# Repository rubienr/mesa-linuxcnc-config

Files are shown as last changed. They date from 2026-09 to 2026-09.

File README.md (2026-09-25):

# LinuxCNC workspace

This repository records the LinuxCNC host, runtime tooling, Mesa communication
benchmark, current machine evidence, and the staged Frida migration from the
BeagleBone/Panther controller to a Mesa 7I95T.

## Project map

| Area | Purpose | Status |
| --- | --- | --- |
| [`archlinux/`](archlinux/) | Arch Linux, PREEMPT_RT, driver, BIOS, and CPU-isolation setup | Host installation record |
| [`config/`](config/) | Affinity and launcher scripts plus `config/frida-mesa/` | Runtime tooling and unverified commissioning profile |
| [`mesa-benchmark/`](mesa-benchmark/) | Repeatable 1 ms/2 ms HostMot2 Ethernet test | Communication-only; not machine control |
| [`hardware-documentation/current/`](hardware-documentation/current/) | Verified hardware, recovered settings, migration evidence, and open work | Current documentation source of truth |
| [`hardware-documentation/legacy/`](hardware-documentation/legacy/) | BBB/Panther schematics and Machinekit configuration | Forensic evidence only |

## Source-of-truth boundaries

- Host installation and tuning rationale: `archlinux/README.md`.
- Runtime CPU/IRQ enforcement: scripts under `config/`.
- Frida LinuxCNC behavior and proposed terminal allocation:
  `config/frida-mesa/` and its `wiring.csv`.
- Current physical-machine facts: topic documents under
  `hardware-documentation/current/`.
- Historical files under `hardware-documentation/legacy/` must be verified
  before their values are reused.

Start with the README in the relevant area. AI coding agents must follow the
root and nearest scoped `AGENTS.md` files before changing this workspace.

## Synchronizing to the target

After making local changes, synchronize the complete workspace to the target
checkout before target-host testing:

```console
./tools/sync-to-target.sh
```

Use `./tools/sync-to-target.sh --dry-run` to preview changes. The wrapper
transfers the workspace to `frida@frida:~/linuxcnc/` over SSH,
excludes `.git`, and does not delete files that exist only on the target.
`TARGET_SSH_DESTINATION` and `TARGET_WORKSPACE` provide explicit overrides when
needed. Generated diagnostic logs, monitor locks, and archived diagnostic runs
remain target-local; only the tracked log-directory placeholders are copied.

## Convenience launchers

From the repository root, `./linuxcnc-start.sh /path/to/config.ini` forwards an
explicit INI to `config/linuxcnc-start.sh` after interactively applying and
checking IRQ affinity. LinuxCNC RTAPI creates its realtime task on CPU 11 via
`RTAPI_CPU_NUMBER`; a second unprivileged check is logged after the task
appears. To launch the communication-only 1 ms Mesa profile in a detached
screen session, use:

```console
./linuxcnc-benchmark-mesa-1ms.sh
screen -r mesa-benchmark-1ms
```

The benchmark launcher refuses to run when it detects an existing LinuxCNC,
LinuxCNC server, or RTAPI process. Override only the screen session name with
`MESA_SCREEN_SESSION`. Affinity logs are written privately below
`mesa-benchmark/diagnostic-logs/`. A failed pre-start affinity check is logged
as a warning and does not prevent startup because the LinuxCNC realtime task
does not exist yet. A setter failure remains fatal, and the delayed post-start
check records the authoritative realtime-task placement.

Run the affinity tools directly from the repository root with:

```console
./thread-affinity-check.sh --brief
./thread-affinity-set.sh
```

These convenience scripts delegate all arguments to their counterparts below
`config/`; the root setter invokes `sudo` and therefore retains its interactive
password prompt.

Manage the graphics stress load and show a concise runtime overview from the
repository root with:

```console
./glxgears-restart.sh
./glxgears-stop.sh
./runtime-status.sh
```

The stop helper stops only the managed `mesa-glxgears-stress.service` and
reports unrelated surviving `glxgears` processes instead of killing them.

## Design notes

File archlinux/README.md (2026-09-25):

# LinuxCNC on Arch Linux with PREEMPT_RT

This is the working installation and tuning record for a Lenovo ThinkCentre
M75q Gen 2 (type 11JK) with a Ryzen 5 PRO 4650GE and Mesa 7I95T. It deliberately
records the Arch-specific failures encountered during setup.

Validated package and firmware versions at the time of writing:

```text
BIOS               M3CKT3EA / 1.62 (2026-01-15)
kernel             linux-rt 7.2.6.rt3.arch1-1
LinuxCNC           2.9.10-1
Mesa utility       mesaflash-git 3.4.9.r33.g11e6f85-1
Realtek driver     r8168-dkms 8.057.00-2
BLT                2.4z-12 (locally patched)
Tcl/Tk             8.6.16-1
```

## 1. Install the realtime kernel

```bash
sudo pacman -Syu
sudo pacman -S linux-rt linux-rt-headers
sudo grub-mkconfig -o /boot/grub/grub.cfg
sudo reboot
```

If `grub-mkconfig` produces only firmware and snapshot entries, verify that
GRUB's Linux generator is executable. This permission was wrong on the
validated installation:

```bash
ls -l /etc/grub.d/10_linux
sudo chmod 755 /etc/grub.d/10_linux
sudo grub-mkconfig -o /boot/grub/grub.cfg
```

After rebooting, verify PREEMPT_RT rather than relying only on the kernel name:

```bash
uname -r
cat /sys/kernel/realtime
```

The second command must print `1`.

## 2. Install build prerequisites and LinuxCNC

Install the normal Arch build tools and `hostname`. The missing `hostname`
program caused part of the LinuxCNC build/runtime setup to fail; on Arch it is
provided by `inetutils`:

```bash
sudo pacman -S --needed base-devel git inetutils
command -v hostname
pacman -Qo /usr/bin/hostname
```

Install the stable LinuxCNC package and current Mesa utility from the AUR:

```bash
yay -S linuxcnc
yay -S mesaflash-git
```

The tested installation uses stable `linuxcnc 2.9.10-1`, not
`linuxcnc-git`. The Git package may be newer but is a moving development
target and is unnecessary for this benchmark.

Verify the realtime helper. The leading `s` in the owner execute position is
intentional for this package:

```bash
pacman -Q linuxcnc
ls -l /usr/bin/rtapi_app
```

Expected permissions begin with `-rwsr-xr-x`. Do not run `modprobe rtapi`:
this configuration uses userspace RTAPI on PREEMPT_RT, so there is no `rtapi`
kernel module. The misleading module message from `halcmd` can also appear
when no LinuxCNC realtime session is running or when `halcmd` is invoked as a
different user.

## 3. Build the BLT Tcl/Tk extension correctly

BLT is required by Tcl/Tk-based tools such as the LinuxCNC latency histogram.
The unmodified AUR `blt` recipe failed in two ways on this system:

- GCC rejected the old spline callback declarations with `too many arguments
  to function` under the newer C language rules.
- `libBLT24.so` was initially built without Tcl/Tk dependencies and later
  failed with an undefined `Tk_MeasureChars` symbol.

Clone the AUR recipe, apply the included patch, and force a clean rebuild:

```bash
mkdir -p "$HOME/builds"
cd "$HOME/builds"
git clone https://aur.archlinux.org/blt.git
cd blt
patch -Np1 < "$HOME/linuxcnc/archlinux/blt-PKGBUILD.patch"
makepkg -Cfsi
```

`-f` matters if an earlier package file exists; `makepkg -Csi` alone can end
up reinstalling an already-built broken package instead of producing the
intended replacement.

Confirm that BLT is linked against both Tk and Tcl:

```bash
readelf -d /usr/lib/libBLT24.so | grep NEEDED
```

The output must include at least `libtk8.6.so` and `libtcl8.6.so` in addition
to the usual system libraries.

Some LinuxCNC latency utilities are intended for a source-tree Run In Place
(RIP) environment. The Mesa benchmark in the sibling directory does not
require a RIP installation.

## 4. Replace `r8169` with `r8168-dkms`

The exact PCI device in the tested computer is:

```text
Realtek RTL8111/8168/8211/8411 PCI Express Gigabit Ethernet Controller
PCI ID:          10ec:8168, revision 15
Subsystem:       Lenovo 17aa:3190
Firmware:        rtl8168h-2_0.0.2 (2015-02-26)
PCI address:     0000:01:00.0
```

The realtime kernel's in-tree `r8169` driver produced rapidly increasing Mesa
packet errors and millisecond-scale HostMot2 read delays on this controller.
The AUR `r8168-dkms` driver was materially better.

The realtime headers must be installed so DKMS builds for `linux-rt`:

```bash
sudo pacman -S --needed dkms linux-rt-headers
yay -S r8168-dkms
sudo mkinitcpio -P
sudo reboot
```

The package installs `/usr/lib/modprobe.d/r8168-dkms.conf` containing:

```text
blacklist r8169
```

Verify the active driver after rebooting:

```bash
lspci -nnk -s 01:00.0
ethtool -i enp1s0
```

The first line must be `driver: r8168`. On the validated system it reports
version `8.057.00-NAPI`.

Configure the dedicated Mesa interface without a gateway or DNS server:

```bash
sudo nmcli connection modify "Mesa LAN" \
    connection.interface-name enp1s0 \
    ipv4.method manual \
    ipv4.addresses 192.168.1.111/24 \
    ipv4.gateway "" \
    ipv4.dns "" \
    ipv4.never-default yes \
    ipv6.method disabled
sudo nmcli connection up "Mesa LAN"
ping -c 3 192.168.1.121
```

## 5. Kernel command line and CPU isolation

A representative `/proc/cmdline` is shown below. The root filesystem UUID is
an installation-specific metavalue, not a UUID that should be copied:

```text
BOOT_IMAGE=/vmlinuz-linux-rt root=UUID=<ROOT_FILESYSTEM_UUID> rw rootflags=subvol=@ loglevel=3 quiet ipv6.disable=1 isolcpus=domain,managed_irq,5,11 nohz_full=5,11 rcu_nocbs=5,11 irqaffinity=0-4,6-10
```

GRUB generates the real `root=UUID=...` argument for the installed root
filesystem. Leave that generation to GRUB; only add the tuning parameters to
`GRUB_CMDLINE_LINUX_DEFAULT`.

The tuning portion in `/etc/default/grub` is:

```bash
GRUB_CMDLINE_LINUX_DEFAULT="loglevel=3 quiet ipv6.disable=1 isolcpus=domain,managed_irq,5,11 nohz_full=5,11 rcu_nocbs=5,11 irqaffinity=0-4,6-10"
```

`ipv6.disable=1` disables IPv6 system-wide at boot: interfaces receive no IPv6
addresses and applications cannot open IPv6 sockets. Use it only when the
Wi-Fi/SSH network is known to work over IPv4. Remove the parameter and reboot
if IPv6 is needed later; see the
[Linux kernel IPv6 documentation](https://www.kernel.org/doc/html/latest/networking/ipv6.html).

The Ryzen 5 PRO 4650GE presents two logical CPUs per physical core. The tested
allocation is:

| Physical core | Logical CPUs | Intended role |
| --- | --- | --- |
| 0 | 0 / 6 | Housekeeping, desktop, stress workers, and Wi-Fi IRQs |
| 1 | 1 / 7 | Housekeeping, desktop, stress workers, and Wi-Fi IRQs |
| 2 | 2 / 8 | CPU 2 idle; CPU 8 dedicated to the Mesa Ethernet IRQ during tests |
| 3 | 3 / 9 | Housekeeping, desktop, stress workers, and Wi-Fi IRQs |
| 4 | 4 / 10 | Housekeeping, desktop, stress workers, and Wi-Fi IRQs |
| 5 | 5 / 11 | CPU 5 isolated and idle; CPU 11 isolated for the LinuxCNC servo thread |

Only CPUs 5 and 11 are kernel-isolated. CPUs 2 and 8 are reserved operationally
by excluding them from the stress workload, pinning the Mesa IRQ to CPU 8, and
keeping Wi-Fi IRQs away from both siblings.

Regenerate the configuration and reboot after changing it:

```bash
sudo grub-mkconfig -o /boot/grub/grub.cfg
sudo reboot
cat /proc/cmdline
cat /sys/devices/system/cpu/isolated
cat /sys/devices/system/cpu/nohz_full
ip -6 address
```

CPUs 5 and 11 should be listed as isolated/nohz-full CPUs. The LinuxCNC FIFO
servo thread runs on CPU 11 and CPU 5 is its idle SMT sibling. With
`ipv6.disable=1`, `ip -6 address` should show no IPv6 addresses.

## 6. Network IRQ placement

CPU isolation does not automatically keep every managed MSI-X vector away
from isolated CPUs. The Intel AX200 Wi-Fi driver initially placed vectors on
both CPU 5 and CPU 11. IRQ numbers also change after each reboot.

Reserve physical core CPU2/8 for Mesa, using CPU 8 for the LAN IRQ, and keep
Wi-Fi away from CPUs 2, 5, 8, and 11:

```bash
LAN_IRQ=$(ls /sys/class/net/enp1s0/device/msi_irqs)
echo 8 | sudo tee "/proc/irq/$LAN_IRQ/smp_affinity_list"

for IRQ in $(ls /sys/class/net/wlp2s0/device/msi_irqs); do
    CPU=$(cat "/proc/irq/$IRQ/effective_affinity_list")
    case "$CPU" in
        2)  TARGET=1 ;;
        5)  TARGET=4 ;;
        8)  TARGET=7 ;;
        11) TARGET=10 ;;
        *)  continue ;;
    esac
    echo "$TARGET" | sudo tee "/proc/irq/$IRQ/smp_affinity_list"
done
```

Some Wi-Fi effective affinities update only after another interrupt. Verify
both requested and effective affinity before starting LinuxCNC:

```bash
for DEV in enp1s0 wlp2s0; do
    echo "=== $DEV ==="
    for IRQ in $(ls "/sys/class/net/$DEV/device/msi_irqs"); do
        printf 'IRQ %-3s requested=' "$IRQ"
        cat "/proc/irq/$IRQ/smp_affinity_list"
        printf '        effective='
        cat "/proc/irq/$IRQ/effective_affinity_list"
    done
done
```

These runtime assignments are not persistent across reboot. Reapply them
after boot until a dedicated systemd unit is installed.

The maintained workspace scripts implement the same dynamic IRQ discovery and
check the LinuxCNC FIFO task once it exists:

```bash
sudo "$HOME/linuxcnc/config/thread-affinity-set.sh"
"$HOME/linuxcnc/config/thread-affinity-check.sh"
```

Run the setter once after boot for the network IRQs. Normal launchers set
`RTAPI_CPU_NUMBER=11` before LinuxCNC creates its realtime task. Use the
setter's explicit `--repair-running-rt` mode only when the post-start check
finds incorrect placement.

The reproducible stress affinity deliberately excludes the two realtime and
two Mesa-network CPUs:

```bash
taskset -c 0-1,3-4,6-7,9-10 \
    stress-ng --cpu 8 --vm 2 --vm-bytes 2G --timeout 24h
```

## 7. BIOS configuration

Installed firmware: Lenovo `M3CKT3EA / 1.62`. The following settings were
applied for the current test:

```text
WirelessLANAccess                 Enabled (required for SSH)
Bluetooth                        Disabled
CStateSupport                    Disabled
ASPMSupport                      Disabled
EnhancedPowerSavingMode          Disabled
OnboardAudioController           Disabled
AMDSecureVirtualMachine (SVM)    Disabled
IOMMU                            Disabled
DASHSupport                      Disabled
Integrated GPU UMA framebuffer   2 GiB
```

The cooling mode was left unchanged; `Full speed` was not selected.
`CPBMode` (AMD boost) was also left unchanged. Change one variable at a time
if either option is tested later.

At runtime, this BIOS configuration results in:

```bash
cat /sys/devices/system/cpu/cpuidle/current_driver
```

printing `none`, confirming that the previous ACPI C2/C3 idle states are no
longer active.

## 8. Final checks

Before a benchmark or machine session, check:

```bash
cat /sys/kernel/realtime
cat /proc/cmdline
ethtool -i enp1s0
ip -4 address show enp1s0
ip -6 address
ping -c 3 192.168.1.121
ls -l /usr/bin/rtapi_app
```

Expected essentials are realtime `1`, the isolation parameters above,
`ipv6.disable=1` when the system-wide IPv6 policy is selected, `r8168`, address
`192.168.1.111/24`, no IPv6 addresses, a reachable Mesa card, and setuid
permissions on `rtapi_app`.

Use `../config/README.md` for the normal operating sequence and
`../mesa-benchmark/README.md` for the 1 ms/2 ms benchmark, load
generation, counters, and safety constraints.

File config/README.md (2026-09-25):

# LinuxCNC runtime and machine configurations

This directory contains the shared CPU/IRQ affinity and launcher scripts plus
the staged Frida Mesa 7I95T commissioning profile under `frida-mesa/`. IRQ
numbers are discovered dynamically because they can change at boot.

## CPU and IRQ layout

| Logical CPU | Intended use |
| --- | --- |
| 0, 1, 3, 4, 6, 7, 9, 10 | Housekeeping, desktop, stress workers, and Wi-Fi IRQs |
| 2 | Keep idle; SMT sibling of the Mesa IRQ CPU |
| 5 | Kernel-isolated and idle; SMT sibling of the servo CPU |
| 8 | Mesa Ethernet IRQ |
| 11 | LinuxCNC FIFO servo thread |

The affinity checker requires Wi-Fi IRQs to stay away from CPUs 2, 5, 8, and
11. CPU 5 and 11 are kernel-isolated; CPU 2 and 8 are reserved operationally
by the affinity and stress scripts.

> **Machine-safety warning:** The benchmark commands its stepgen enables and
> isolated SSR outputs false, but it is not a safety system. The Frida profile
> is not yet a verified machine configuration. Remove hazardous actuator power,
> use a hard E-stop, and verify wiring and polarity before commissioning work.

## Shared operating sequence

Apply network IRQ affinity once after each boot:

```bash
sudo ./thread-affinity-set.sh
```

The normal setter changes network IRQ placement only. LinuxCNC userspace RTAPI
receives `RTAPI_CPU_NUMBER=11` before launch so the realtime task starts on its
intended CPU. Use `sudo ./thread-affinity-set.sh --repair-running-rt` only when
the checker finds that an already-running RTAPI task has the wrong affinity.

The launcher intentionally has no default INI. Name the configuration so the
benchmark cannot be started accidentally on a connected machine:

```bash
LIBGL_ALWAYS_SOFTWARE=0 ./linuxcnc-start.sh \
    ../mesa-benchmark/mesa-7i95t-bench-1ms.ini
```

Once LinuxCNC is open, verify the new FIFO thread. The repository-root
convenience launchers perform this check automatically:

```bash
./thread-affinity-check.sh
```

Use `--brief` for a one-line result or `--wait-for-rt SECONDS` during startup.
Detailed IRQ output includes the current kernel handler description from
`/proc/interrupts`, such as `enp1s0-0` or `iwlwifi:default_queue`, so changing
IRQ numbers remain identifiable after a reboot.

`LIBGL_ALWAYS_SOFTWARE=0` selects hardware rendering. If AXIS crashes because
of a GPU/driver problem, retry diagnostically with
`LIBGL_ALWAYS_SOFTWARE=1`. Software rendering increases CPU load and may worsen
realtime latency, so repeat the Mesa and servo checks before relying on it.

The scripts accept `LAN_INTERFACE`, `WIFI_INTERFACE`, `LAN_IRQ_CPU`, and
`SERVO_CPU` overrides. Defaults match the host and kernel parameters documented
in `../archlinux/README.md`.

## Frida Mesa 7I95T commissioning profile

`frida-mesa/` migrates the three-axis Frida machine from the BeagleBone
Black/Panther Cape to LinuxCNC 2.9.10 and a Mesa 7I95T. It is based on the last
active Machinekit configuration, the revision 0.19 legacy schematic, current
hardware evidence, and the Mesa/Leadshine manuals.

Wire identities, polarities, voltage domains, hard E-stop behavior, travel,
and homing directions still require physical verification. All six Mesa SSR
outputs and the three unused step generators are commanded off. The three
unidentified two-wire cable bundles must remain insulated until traced.

### Profile files

- `frida-mesa/frida-mesa.ini`: machine, trajectory, joint, homing, and component
  settings.
- `frida-mesa/mesa.hal`: HostMot2 Ethernet load, thread order, and X/Y/Z step
  generators.
- `frida-mesa/general-signals.hal`: E-stop, limits, legacy homing, probe,
  alarms, and tool loopbacks.
- `frida-mesa/hy-vfd.hal`: Huanyang control through the existing USB/RS-485
  adapter.
- `frida-mesa/pendant.hal`: XHC WHB04B-6 integration.
- `frida-mesa/motion.hal`: final servo-thread ordering.
- `frida-mesa/wiring.csv`: proposed terminal-level allocation and eventual
  wiring source of truth.
- `frida-mesa/udev/70-xhc-whb04b-6.rules`: desktop-seat access for the pendant.

Hazardous legacy probe/tool-change MDI macros are not enabled. Pendant macro,
machine-home, safe-Z, work-home, probe-Z, and Fn-modified buttons remain
unassigned until the old NGC routines are reviewed and tested with spindle and
drive power removed.

### Allocation and electrical assumptions

- Step generators 0, 1, and 2 are X, Y, and Z on TB3.
- TB6 pairs group X, X, Y, Y, Z, probe, E-stop, and spare inputs.
- TB5 inputs 16 through 18 are X, Y, and Z drive alarms; 19 through 23 are
  reserved for traced future wiring.
- TB5 outputs 0 through 5 are unassigned.
- TB4 serial is unused because the current firmware exposes no PktUART HAL
  interface compatible with the existing `hy_vfd` tty path.

The initial step/direction allocation retains the existing common-anode wiring:

| Axis | Mesa terminals | AM882 terminals |
| --- | --- | --- |
| X | TB3-6 `+5VP`, TB3-2 `STEP0-`, TB3-4 `DIR0-` | PUL+/DIR+, PUL-, DIR- |
| Y | TB3-12 `+5VP`, TB3-8 `STEP1-`, TB3-10 `DIR1-` | PUL+/DIR+, PUL-, DIR- |
| Z | TB3-18 `+5VP`, TB3-14 `STEP2-`, TB3-16 `DIR2-` | PUL+/DIR+, PUL-, DIR- |

Leave STEP+/DIR+ and GND unconnected during this phase; never tie the unused
complementary output to ground or +5 V. Prove every conductor and drive-side
terminal before connection.

The eight limit/home sensors are NPN normally closed. The HAL uses HostMot2
`-not` pins so a target or broken output conductor appears asserted. Confirm
the sensor supply is within the Mesa input's 4--36 VDC range. For each sensor
pair, the proposal connects `INCOM` to fused sensor positive, black output to
the allocated input, and blue to sensor-supply 0 V. The recovered homing
behavior is X on X-, Y on Y+, and Z on Z+; dedicated X/Y home sensors remain
diagnostic until their positions and directions are tested.

`ESTOP_OK` on TB6 input 12 is status from the hardwired safety chain, not an
E-stop output. The hard circuit must remove hazardous energy independently.
Legacy evidence suggests probe and E-stop are positive-voltage switch signals,
with their paired `INCOM` terminals at field 0 V; prove this and do not share
their commons with the NPN sensor pairs.

The proposed drive-alarm circuit connects each Mesa `INCOM` to fused field
positive, `INPUT` to AM882 `ALM+`, and `ALM-` to field 0 V. Confirm polarity,
normal/fault states, and the shared-common arrangement before using a raw input
as a joint fault. An open-collector alarm is not automatically fail-safe for a
broken conductor.

Do not move the unresolved legacy `DRIVER_ENABLE` circuit to a Mesa SSR output.
Its `SW4A` annotation and ENA polarity/reset behavior must be traced with drive
power isolated. Disabling a step generator stops pulses but may leave motor
torque enabled.

The VFD profile retains the known tty path at 19,200 baud, 8N1, address 1:

```text
/dev/serial/by-id/usb-1a86_USB_Serial-if00-port0
```

The current CH340C/MAX485 adapter is not galvanically isolated. Verify serial
polarity, shielding, motor data, control-source parameters, and communication
loss behavior before energizing the spindle.

Install the pendant access rule locally, then reconnect the receiver:

```bash
sudo install -m 0644 frida-mesa/udev/70-xhc-whb04b-6.rules \
    /etc/udev/rules.d/70-xhc-whb04b-6.rules
sudo udevadm control --reload-rules
```

Test every selector, wheel mode, and button with drives and spindle disabled.

### Commissioning order

1. Disconnect mains loads, stepper supply, and VFD/spindle power; bond Mesa
   frame ground and verify its regulated 5 V supply.
2. Label and continuity-test every legacy conductor and complete the missing
   fields in `frida-mesa/wiring.csv`.
3. Connect only Ethernet, Mesa 5 V, field-input supply, and inputs; verify raw
   and inverted pins with HAL tools.
4. Prove every E-stop device and safety-chain power loss opens `ESTOP_OK` and
   independently removes hazardous energy.
5. With motor power removed, connect step/direction and verify idle levels and
   polarity at each drive plug.
6. Energize one drive at a time at low velocity and acceleration; establish
   direction and both limits before homing.
7. Re-measure travel and braking margin; test Z first, then X and Y.
8. Validate the pendant with spindle disabled and macros unassigned.
9. Bench-test the VFD with the spindle power stage safe, including stop on
   E-stop, LinuxCNC exit, USB removal, timeout, and power loss.
10. Record final wiring before considering differential step/direction.

Launch only when no other LinuxCNC/HAL realtime session is active:

```bash
sudo ./thread-affinity-set.sh
RTAPI_CPU_NUMBER=11 LIBGL_ALWAYS_SOFTWARE=0 \
    ./linuxcnc-start.sh ./frida-mesa/frida-mesa.ini
```

Detailed physical evidence and open verification work live under
`../hardware-documentation/current/`.

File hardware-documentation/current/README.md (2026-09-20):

# Current CNC hardware documentation

This directory is the current source of truth for the machine during migration
to LinuxCNC and a Mesa 7I95T. It separates confirmed physical evidence from
legacy-derived settings and unresolved assumptions so a task can load only the
relevant topic.

The files under
[`../legacy/beaglebone-black-panther-cape/`](../legacy/beaglebone-black-panther-cape/)
are forensic references. They must not be treated as correct for the current
machine without verification.

## Status labels

- **Confirmed**: stated by the owner or unambiguously recorded in current
  physical evidence.
- **Legacy-derived**: recovered from the old configuration or documentation;
  verify before energizing the rebuilt machine.
- **To verify**: plausible or shown in a drawing, but not confirmed physically.

## Topic index

| Topic | Read |
| --- | --- |
| Installed devices, power supplies, model identities, datasheet index | [`inventory.md`](inventory.md) |
| Motors, drives, coordinates, homing, limits, and sensor interface | [`motion.md`](motion.md) |
| Spindle, Huanyang VFD, coolant, RS-485, and register capture | [`spindle-vfd.md`](spindle-vfd.md) |
| Tool sensing, touch-off, pendant, and front-panel controls | [`controls-and-probing.md`](controls-and-probing.md) |
| Errors in the legacy schematic and the wiring-record format | [`legacy-and-wiring.md`](legacy-and-wiring.md) |
| Unresolved decisions and physical verification work | [`TODO.md`](TODO.md) |
| VFD parameter backup description | [`huanyang-hy02d223b-register-backup.md`](huanyang-hy02d223b-register-backup.md) |
| Generated VFD parameter table | [`huanyang-hy02d223b-register-backup-table.md`](huanyang-hy02d223b-register-backup-table.md) |

The proposed current terminal allocation is
[`../../config/frida-mesa/wiring.csv`](../../config/frida-mesa/wiring.csv).

## Safety boundary

This documentation is not an approved wiring diagram. Do not inspect,
disconnect, or measure energized mains equipment. Do not energize the spindle,
stepper drives, pump, vacuum equipment, or other mains loads from the benchmark
configuration. Verify protective earth, fusing, conductor sizes, isolation,
contact ratings, emergency-stop behavior, and every Mesa I/O voltage before
connecting field wiring.

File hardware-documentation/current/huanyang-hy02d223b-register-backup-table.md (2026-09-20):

| Parameter | Raw | Decoded/current setting | Factory setting | Set range | Unit | Modified [1] | Reserved [2] | Name | What it controls |
| --- | ----: | --- | --- | --- | --- | :---: | :---: | --- | --- |
| `PD000` | 0 | 0 | 0 | 0–1 | 1 | | | Parameter lock | Prevents accidental parameter changes when locked. |
| `PD001` | 2 | 2: communications | 0 | 0–2 | 1 | Y | | Source of operation commands | Selects keypad, external terminals, or communications for run commands. |
| `PD002` | 2 | 2: communications | 0 | 0–3 | 1 | Y | | Source of operating frequency | Selects keypad, analog input, or communications as the frequency source. |
| `PD003` |  4196 | 41.96 Hz | 0.00 Hz | 0.00–400.00  | 0.01 Hz | Y | | Main frequency | Frequency command used in keypad/main-speed operation. |
| `PD004` | 40000 | 400 Hz | 50.00 Hz | 0.01–400.00  | 0.1 Hz  | Y | | Base frequency | Motor V/f base frequency; must match the motor/application. |
| `PD005` | 40000 | 400 Hz | 50.00 Hz | 10.00–400.00 | 0.01 Hz | Y | | Maximum operating frequency | Hard upper operating-frequency setting. |
| `PD006` |  2000 | 20 Hz | 2.50 Hz | 0.01–400.00  | 0.01 Hz | Y | | Intermediate frequency | Intermediate point of the V/f curve. |
| `PD007` | 300 | 3 Hz | 0.50 Hz | 0.10–20.00 | 0.01 Hz | Y | | Minimum frequency | Minimum starting point of the V/f curve. |
| `PD008` |  2200 | 220 V | 220/380 V | 0.1–* | 0.1 V | | | Maximum voltage | Maximum V/f-curve voltage. |
| `PD009` | 200 | 20 V | 15/27.5 V | 0.1–500.0 | 0.1 V | Y | | Intermediate voltage | Intermediate V/f-curve voltage. |
| `PD010` | 160 | 16 V | * (8 V for 220 V class; 13.5 V for 380 V class)  | 0.1–50.0 | 0.1 V | Y | | Minimum voltage | Minimum V/f-curve voltage. |
| `PD011` |  1340 | 13.4 Hz | 0.00 Hz | 0.00–400.00  | 0.01 Hz | Y | | Frequency lower limit | Prevents commands below this output frequency. |
| `PD012` | — | Unsupported by this VFD (CRC-checked `0x81` reply) | Reserved; none stated | | | ? | R | Reserved | Reserved in the handbook delivered with this VFD. |
| `PD013` | 88 | 88 | 00 | 00–10 | 1 | Y | | Parameter reset | Writing the reset code can restore factory parameters; read only in this capture. |
| `PD014` | 40 | 4 s | * (model-specific) | 0.1–6500.0 | 0.1 s | ? | | Acceleration time 1 | Sets one of four acceleration/deceleration ramp times. |
| `PD015` | 50 | 5 s | * (model-specific) | 0.1–6500.0 | 0.1 s | ? | | Deceleration time 1 | Sets one of four acceleration/deceleration ramp times. |
| `PD016` | 200 | 20 s | * (model-specific) | 0.1–6500.0 | 0.1 s | ? | | Acceleration time 2 | Sets one of four acceleration/deceleration ramp times. |
| `PD017` | 200 | 20 s | * (model-specific) | 0.1–6500.0 | 0.1 s | ? | | Deceleration time 2 | Sets one of four acceleration/deceleration ramp times. |
| `PD018` | 400 | 40 s | * (model-specific) | 0.1–6500.0 | 0.1 s | ? | | Acceleration time 3 | Sets one of four acceleration/deceleration ramp times. |
| `PD019` | 400 | 40 s | * (model-specific) | 0.1–6500.0 | 0.1 s | ? | | Deceleration time 3 | Sets one of four acceleration/deceleration ramp times. |
| `PD020` | 800 | 80 s | * (model-specific) | 0.1–6500.0 | 0.1 s | ? | | Acceleration time 4 | Sets one of four acceleration/deceleration ramp times. |
| `PD021` | 800 | 80 s | * (model-specific) | 0.1–6500.0 | 0.1 s | ? | | Deceleration time 4 | Sets one of four acceleration/deceleration ramp times. |
| `PD022` | 0 | 0 | Reserved; none stated | | | ? | R | Reserved | Reserved in the handbook delivered with this VFD. |
| `PD023` | 0 | 0: reverse forbidden | 1 | 0–1 | 1 | Y | | Reverse-rotation selection | Allows or forbids reverse motor rotation. |
| `PD024` | 1 | 1: panel STOP valid | 1 | 0–1 | 1 | | | STOP-key selection | Determines whether the panel STOP key remains effective under remote control. |
| `PD025` | 0 | 0: normal start | 0 | 0–1 | 1 | | | Starting mode | Selects normal start or frequency-track start. |
| `PD026` | 0 | 0: decelerating stop | 0 | 0–1 | 1 | | | Stopping mode | Selects ramped stop or coast stop. |
| `PD027` | 50 | 5 Hz | 0.5 Hz | 0.1–10.0 | 0.1 Hz  | Y | | Starting frequency | Initial output frequency during a normal start. |
| `PD028` | 50 | 5 Hz | 0.5 Hz | 0.1–10.0 | 0.1 Hz  | Y | | Stopping frequency | Frequency at which normal deceleration transitions to stop/braking. |
| `PD029` | 0 | 0 s | 0.0 s | 0.0–25.0 | 0.1 s | | | DC-braking time at start | Duration of DC injection before starting. |
| `PD030` | 0 | 0 s | 0.0 s | 0.0–25.0 | 0.1 s | | | DC-braking time at stop | Duration of DC injection during stopping. |
| `PD031` | 20 | 2 % | 2.0% | 0.0–20.0 | 0.1% | | | DC-braking voltage level | DC-injection braking voltage as a percentage. |
| `PD032` | 50 | 5 s | 2.0 s | 0.1–20.0 | 0.1 s | Y | | Frequency-track time | Time used to search for the speed of a spinning load. |
| `PD033` | 150 | 150 % | 150% | 0–200 | 1% | | | Current level for frequency tracking | Current limit used during frequency tracking. |
| `PD034` | 5 | 0.5 s | 0.5 s | 0.1–10.0 | 0.1 s | | | Voltage-rise time during frequency tracking | Voltage-rise timing during frequency tracking. |
| `PD035` | — | Unsupported by this VFD (CRC-checked `0x81` reply) | Reserved; none stated | | | ? | R | Reserved | Reserved in the handbook delivered with this VFD. |
| `PD036` | — | Unsupported by this VFD (CRC-checked `0x81` reply) | Reserved; none stated | | | ? | R | Reserved | Reserved in the handbook delivered with this VFD. |
| `PD037` | — | Unsupported by this VFD (CRC-checked `0x81` reply) | Reserved; none stated | | | ? | R | Reserved | Reserved in the handbook delivered with this VFD. |
| `PD038` | — | Unsupported by this VFD (CRC-checked `0x81` reply) | Reserved; none stated | | | ? | R | Reserved | Reserved in the handbook delivered with this VFD. |
| `PD039` | — | Unsupported by this VFD (CRC-checked `0x81` reply) | Reserved; none stated | | | ? | R | Reserved | Reserved in the handbook delivered with this VFD. |
| `PD040` | — | Unsupported by this VFD (CRC-checked `0x81` reply) | Reserved; none stated | | | ? | R | Reserved | Reserved in the handbook delivered with this VFD. |
| `PD041` | 15 | 20 kHz | 5 (generic; model-dependent) | 0–15 | 1 | Y | | Carrier frequency | PWM carrier selection; trades motor noise against VFD heating/EMI. |
| `PD042` | 500 | 5 Hz | 5.00 Hz | 0.00–400.00  | 0.01 Hz | | | Jogging frequency | Output frequency used for jog operation. |
| `PD043` | 0 | 0 | 1 s | 0–6500 | 1 s | Y | | S-curve time | Softens acceleration/deceleration transitions when nonzero. |
| `PD044` | 2 | 2: forward | 02 | 00–32 | 1 | | | Multi-input 1 (FOR terminal) | Assigns a function to one of the six digital input terminals. |
| `PD045` | 3 | 3: reverse | 03 | 00–32 | 1 | | | Multi-input 2 (REV terminal) | Assigns a function to one of the six digital input terminals. |
| `PD046` | 14 | 14: timer 2 start | 10 | 00–32 | 1 | Y | | Multi-input 3 (RST terminal) | Assigns a function to one of the six digital input terminals. |
| `PD047` | 22 | 22: multi-speed 3 | 17 | 00–32 | 1 | Y | | Multi-input 4 (SPH terminal) | Assigns a function to one of the six digital input terminals. |
| `PD048` | 24 | 24: ramp-time select 2 | 18 | 00–32 | 1 | Y | | Multi-input 5 (SPM terminal) | Assigns a function to one of the six digital input terminals. |
| `PD049` | 23 | 23: ramp-time select 1 | 19 | 00–32 | 1 | Y | | Multi-input 6 (SPL terminal) | Assigns a function to one of the six digital input terminals. |
| `PD050` | 1 | 1: in run | 01 | 00–32 | 1 | | | Multi-output 1 (DRV) | Assigns a status/control function to a multifunction output. |
| `PD051` | 5 | 5: set frequency reached | 05 | 00–32 | 1 | | | Multi-output 2 (UPF) | Assigns a status/control function to a multifunction output. |
| `PD052` | 8 | 8: accelerating | 02 | 00–32 | 1 | Y | | Multi-output 3 (FA/FB/FC) | Assigns a status/control function to a multifunction output. |
| `PD053` | 0 | 0: disabled | 00 | 00–32 | 1 | | | Multi-output 4 (KA/KB) | Assigns a status/control function to a multifunction output. |
| `PD054` | 0 | 0: 0–10 V proportional to output frequency | 0 | 0–7 | 1 | | | AM analog/pulse-output selection | Selects what the AM terminal represents and whether it is analog or pulse output. |
| `PD055` | 100 | 10 % | 100.0% | 0.0–100.0 | 0.1% | Y | | AM analog-output gain | Scales the AM monitor output. |
| `PD056` | 0 | 0 Hz | 0.00 Hz | 0.00–400.00  | 0.01 Hz | | | Skip frequency 1 | Defines a frequency to skip to avoid mechanical resonance. |
| `PD057` | 0 | 0 Hz | 0.00 Hz | 0.00–400.00  | 0.01 Hz | | | Skip frequency 2 | Defines a frequency to skip to avoid mechanical resonance. |
| `PD058` | 0 | 0 Hz | 0.00 Hz | 0.00–400.00  | 0.01 Hz | | | Skip frequency 3 | Defines a frequency to skip to avoid mechanical resonance. |
| `PD059` | 50 | 0.5 Hz | 0.50 Hz | 0.10–10.00 | 0.01 Hz | | | Skip-frequency range | Half-width around each avoided mechanical-resonance frequency. |
| `PD060` | 10000 | 100 Hz | 0.00 Hz | 0.00–400.00  | 0.01 Hz | Y | | Uniform frequency 1 | Frequency threshold used by multifunction outputs and pump control. |
| `PD061` |  3500 | 35 Hz | 0.00 Hz | 0.00–400.00  | 0.01 Hz | Y | | Uniform frequency 2 | Frequency threshold used by multifunction outputs and pump control. |
| `PD062` |  1000 | 10 Hz | 0.50 Hz | 0.10–10.00 | 0.01 Hz | Y | | Uniform-frequency range | Hysteresis around the uniform-frequency thresholds. |
| `PD063` | 1 | 0.1 s | 0.01 | 0.1–10.0 | 0.1 s | | | Timer 1 time | Delay for an externally triggered multifunction timer. |
| `PD064` | 1 | 1 s | 0 | 1–100 | 1 s | Y | | Timer 2 time | Delay for an externally triggered multifunction timer. |
| `PD065` | 0 | 0 | 0 | 0–65500 | 1 | | | Counting value | Final external-counter threshold. |
| `PD066` | 0 | 0 | 0 | 0–65500 | 1 | | | Intermediate counter | Intermediate external-counter threshold. |
| `PD067` | — | Unsupported by this VFD (CRC-checked `0x81` reply) | Reserved; none stated | | | ? | R | Reserved | Reserved in the handbook delivered with this VFD. |
| `PD068` | — | Unsupported by this VFD (CRC-checked `0x81` reply) | Reserved; none stated | | | ? | R | Reserved | Reserved in the handbook delivered with this VFD. |
| `PD069` | — | Unsupported by this VFD (CRC-checked `0x81` reply) | Reserved; none stated | | | ? | R | Reserved | Reserved in the handbook delivered with this VFD. |
| `PD070` | 1 | 1: 0–5 V | 0 | 0–4 | 1 | Y | | Analog-input type | Selects voltage/current analog command input behavior. |
| `PD071` | 20 | 20 | 20 | 0–50 | 1 | | | Analog filtering constant | Low-pass filtering of the analog command input. |
| `PD072` | 40000 | 400 Hz | 50.00 Hz | 0.00–400.00  | 0.01 Hz | Y | | Higher analog frequency | Frequency corresponding to the high end of the analog input. |
| `PD073` | 0 | 0 Hz | 0.00 Hz | 0.00–400.00  | 0.01 Hz | | | Lower analog frequency | Frequency corresponding to the low end of the analog input. |
| `PD074` | 0 | 0: positive | 0 | 0–1 | 1 | | | Bias direction at higher frequency | Direction associated with the high end of the analog input. |
| `PD075` | 0 | 0: positive | 0 | 0–1 | 1 | | | Bias direction at lower frequency | Direction associated with the low end of the analog input. |
| `PD076` | 0 | 0: disabled/not retained | 0 | 0–1 | 1 | | | Analog negative-bias reverse | Allows or blocks reverse operation caused by negative analog bias. |
| `PD077` | 0 | 0: disabled/not retained | 0 | 0–1 | 1 | | | UP/DOWN memory | Controls whether an UP/DOWN change survives stopping. |
| `PD078` | 0 | 0: disabled/not retained | 0 | 0–1 | 1 | | | UP/DOWN speed unit | Selects the minimum UP/DOWN step rate. |
| `PD079` | 1 | 1 | Reserved; none stated | | | ? | R | Reserved | Reserved in the handbook delivered with this VFD. |
| `PD080` | 0 | 0: normal operation | 0 | 0–5 | 1 | | | PLC operation mode | Selects normal, multi-speed, traverse, internal PLC, or drawing operation. |
| `PD081` | 0 | 0 (interpretation pending handbook transcription) | Pending handbook transcription | 0–3 | 1 | ? | | Pending transcription from delivered handbook | The project PDF's description is not applicable; transcribe the delivered handbook. |
| `PD082` | 0 | 0 (interpretation pending handbook transcription) | Pending handbook transcription | 0–255 | 1 | ? | | Pending transcription from delivered handbook | The project PDF's description is not applicable; transcribe the delivered handbook. |
| `PD083` | 0 | 0 (interpretation pending handbook transcription) | Pending handbook transcription | 0–255 | 1 | ? | | Pending transcription from delivered handbook | The project PDF's description is not applicable; transcribe the delivered handbook. |
| `PD084` | 0 | 0 (interpretation pending handbook transcription) | Pending handbook transcription | 0–65535 | 1 | ? | | Pending transcription from delivered handbook | The project PDF's description is not applicable; transcribe the delivered handbook. |
| `PD085` | 0 | 0 (interpretation pending handbook transcription) | Pending handbook transcription | 0–65535 | 1 | ? | | Pending transcription from delivered handbook | The project PDF's description is not applicable; transcribe the delivered handbook. |
| `PD086` |  1500 | 15 Hz | 15 Hz | 0.00–400.00  | 0.01 Hz | | | Multi-speed frequency 2 | Frequency command for a multi-speed/PLC step. |
| `PD087` |  2000 | 20 Hz | 20 Hz | 0.00–400.00  | 0.01 Hz | | | Multi-speed frequency 3 | Frequency command for a multi-speed/PLC step. |
| `PD088` |  2500 | 25 Hz | 25 Hz | 0.00–400.00  | 0.01 Hz | | | Multi-speed frequency 4 | Frequency command for a multi-speed/PLC step. |
| `PD089` |  3000 | 30 Hz | 30 Hz | 0.00–400.00  | 0.01 Hz | | | Multi-speed frequency 5 | Frequency command for a multi-speed/PLC step. |
| `PD090` |  3500 | 35 Hz | 35 Hz | 0.00–400.00  | 0.01 Hz | | | Multi-speed frequency 6 | Frequency command for a multi-speed/PLC step. |
| `PD091` |  4000 | 40 Hz | 40 Hz | 0.00–400.00  | 0.01 Hz | | | Multi-speed frequency 7 | Frequency command for a multi-speed/PLC step. |
| `PD092` | 50 | 0.5 Hz | 0.5 Hz | 0.00–400.00  | 0.01 Hz | | | Multi-speed frequency 8 | Frequency command for a multi-speed/PLC step. |
| `PD093` |  1000 | 10 Hz | Pending handbook transcription | 0.00–400.00  | 0.01 Hz | ? | | Multi-speed frequency 9 | Frequency command for a multi-speed/PLC step. |
| `PD094` |  1500 | 15 Hz | Pending handbook transcription | 0.00–400.00  | 0.01 Hz | ? | | Multi-speed frequency 10 | Frequency command for a multi-speed/PLC step. |
| `PD095` |  2000 | 20 Hz | Pending handbook transcription | 0.00–400.00  | 0.01 Hz | ? | | Multi-speed frequency 11 | Frequency command for a multi-speed/PLC step. |
| `PD096` |  2500 | 25 Hz | Pending handbook transcription | 0.00–400.00  | 0.01 Hz | ? | | Multi-speed frequency 12 | Frequency command for a multi-speed/PLC step. |
| `PD097` |  3000 | 30 Hz | Pending handbook transcription | 0.00–400.00  | 0.01 Hz | ? | | Multi-speed frequency 13 | Frequency command for a multi-speed/PLC step. |
| `PD098` |  3500 | 35 Hz | Pending handbook transcription | 0.00–400.00  | 0.01 Hz | ? | | Multi-speed frequency 14 | Frequency command for a multi-speed/PLC step. |
| `PD099` |  4000 | 40 Hz | Pending handbook transcription | 0.00–400.00  | 0.01 Hz | ? | | Multi-speed frequency 15 | Frequency command for a multi-speed/PLC step. |
| `PD100` |  4500 | 45 Hz | Pending handbook transcription | 0.00–400.00  | 0.01 Hz | ? | | Multi-speed frequency 16 | Frequency command for a multi-speed/PLC step. |
| `PD101` | 100 | 10 s | 10.0 s | 0.0–6500.0 | 0.1 s | | | PLC timer 1 | Run duration for a multi-speed/PLC step. |
| `PD102` | 100 | 10 s | 10.0 s | 0.0–6500.0 | 0.1 s | | | PLC timer 2 | Run duration for a multi-speed/PLC step. |
| `PD103` | 0 | 0 s | 0.0 s | 0.0–6500.0 | 0.1 s | | | PLC timer 3 | Run duration for a multi-speed/PLC step. |
| `PD104` | 0 | 0 s | 0.0 s | 0.0–6500.0 | 0.1 s | | | PLC timer 4 | Run duration for a multi-speed/PLC step. |
| `PD105` | 0 | 0 s | 0.0 s | 0.0–6500.0 | 0.1 s | | | PLC timer 5 | Run duration for a multi-speed/PLC step. |
| `PD106` | 0 | 0 s | 0.0 s | 0.0–6500.0 | 0.1 s | | | PLC timer 6 | Run duration for a multi-speed/PLC step. |
| `PD107` | 0 | 0 s | 0.0 s | 0.0–6500.0 | 0.1 s | | | PLC timer 7 | Run duration for a multi-speed/PLC step. |
| `PD108` | 0 | 0 s | 0.0 s | 0.0–6500.0 | 0.1 s | | | PLC timer 8 | Run duration for a multi-speed/PLC step. |
| `PD109` | 0 | 0 s | Pending handbook transcription | 0.0–6500.0 | 0.1 s | ? | | PLC timer 9 | Run duration for a multi-speed/PLC step. |
| `PD110` | 0 | 0 s | Pending handbook transcription | 0.0–6500.0 | 0.1 s | ? | | PLC timer 10 | Run duration for a multi-speed/PLC step. |
| `PD111` | 0 | 0 s | Pending handbook transcription | 0.0–6500.0 | 0.1 s | ? | | PLC timer 11 | Run duration for a multi-speed/PLC step. |
| `PD112` | 0 | 0 s | Pending handbook transcription | 0.0–6500.0 | 0.1 s | ? | | PLC timer 12 | Run duration for a multi-speed/PLC step. |
| `PD113` | 0 | 0 s | Pending handbook transcription | 0.0–6500.0 | 0.1 s | ? | | PLC timer 13 | Run duration for a multi-speed/PLC step. |
| `PD114` | 0 | 0 s | Pending handbook transcription | 0.0–6500.0 | 0.1 s | ? | | PLC timer 14 | Run duration for a multi-speed/PLC step. |
| `PD115` | 0 | 0 s | Pending handbook transcription | 0.0–6500.0 | 0.1 s | ? | | PLC timer 15 | Run duration for a multi-speed/PLC step. |
| `PD116` | 0 | 0 s | Pending handbook transcription | 0.0–6500.0 | 0.1 s | ? | | PLC timer 16 | Run duration for a multi-speed/PLC step. |
| `PD117` | 0 | 0: disabled/not retained | 0 | 0–1 | 1 | | | Auto-PLC memory | Controls whether Auto-PLC resumes its saved state. |
| `PD118` | 1 | 1: enabled/retained | 1 | 0–1 | 1 | | | Over-voltage stall prevention | Extends deceleration when regenerative energy raises the DC bus. |
| `PD119` | 0 | 0 % | 150% | 0–200 | 1% | Y | | Stall-prevention level during acceleration | Current threshold that pauses acceleration. |
| `PD120` | 0 | 0 % | 0% | 0–200 | 1% | | | Stall-prevention level at constant speed | Current threshold that reduces frequency at constant speed. |
| `PD121` | 50 | 5 s | 5.0 s | 0.1–25.5 | 0.1 s | | | Deceleration time for constant-speed stall prevention | Rate used to lower frequency during constant-speed stall prevention. |
| `PD122` | — | Unsupported by this VFD (CRC-checked `0x81` reply) | 150% | 0–200 | 1% | ? | | Stall-prevention level during deceleration | Current threshold used during deceleration. |
| `PD123` | 0 | 0: detect at set frequency and continue running | 0 | 0–3 | 1 | | | Over-torque detection mode | Selects when over-torque is detected and whether it trips. |
| `PD124` | 0 | 0 % | 0% | 0–200 | 1% | | | Over-torque detection level | Current threshold for over-torque detection. |
| `PD125` | 10 | 1 s | 1.0 s | 0.1–20.0 | 0.1 s | | | Over-torque detection time | Delay before over-torque protection acts. |
| `PD126` | 0 | 0 | Not present in project PDF | 0–1 | 1 | ? | N | Not present in project PDF | No applicable description is available yet; preserve the raw result. |
| `PD127` | — | Unsupported by this VFD (CRC-checked `0x81` reply) | Not present in project PDF | | | ? | N | Not present in project PDF | No applicable description is available yet; preserve the raw result. |
| `PD128` | — | Unsupported by this VFD (CRC-checked `0x81` reply) | Not present in project PDF | | | ? | N | Not present in project PDF | No applicable description is available yet; preserve the raw result. |
| `PD129` | — | Unsupported by this VFD (CRC-checked `0x81` reply) | Not present in project PDF | | | ? | N | Not present in project PDF | No applicable description is available yet; preserve the raw result. |
| `PD130` | 1 | 1 auxiliary pump | 0 | 0–2 | 1 | Y | | Number of auxiliary pumps | Configures the number of auxiliary pumps controlled by the VFD. |
| `PD131` | 60 | 60 min | 60 min | 1–9000 | 1 min | | | Continuous running time of auxiliary pumps | Alternation interval for auxiliary pumps. |
| `PD132` | 5 | 5 s | 5 s | 1–250 | 1 s | | | Auxiliary-pump interlocking time | Dead time while changing auxiliary pumps. |
| `PD133` | 5 | 5 s | 60 s | 1–250 | 1 s | Y | | High-speed running time | Delay at high-speed threshold before adding a pump. |
| `PD134` | 5 | 5 s | 60 s | 1–250 | 1 s | Y | | Low-speed running time | Delay at low-speed threshold before removing a pump. |
| `PD135` | 40 | 40 % | 95% | 1–150 | 1% | Y | | Stopping voltage level | Process-feedback threshold for entering sleep. |
| `PD136` | 5 | 5 s | 30 s | 1–250 | 1 s | Y | | Duration at stopping-voltage level | Required duration below the stopping threshold. |
| `PD137` | 20 | 20 % | 80% | 1–150 | 1% | Y | | Wake-up voltage level | Process-feedback threshold for waking from sleep. |
| `PD138` |  1400 | 14 Hz | 20.00 Hz | 0.00–400.00  | 0.01 Hz | Y | | Sleep frequency | Low operating frequency used when entering sleep. |
| `PD139` | 5 | 5 s | 20 s | 1–250 | 1 s | Y | | Duration at sleep frequency | Required duration at the sleep frequency. |
| `PD140` | — | Unsupported by this VFD (CRC-checked `0x81` reply) | Not present in project PDF | | | ? | N | Not present in project PDF | No applicable description is available yet; preserve the raw result. |
| `PD141` |  2200 | 220 V | * (220 V for 230 V class; 380 V for 400 V class) | | 0.1 V | | | Rated motor voltage | Motor nameplate voltage used by protection/control calculations. |
| `PD142` | 100 | 10 A | * | | 0.1 A | ? | | Rated motor current | Motor nameplate current used for current limiting and protection. |
| `PD143` | 2 | 2 poles | 04 | 02–10 | 1 | Y | | Motor pole count | Motor pole count used for speed calculation. |
| `PD144` |  3000 | 3000 rpm at 50 Hz | 1440 rpm | 0–9999 | 1 rpm | Y | | Rated motor speed at 50 Hz | Motor rated speed at 50 Hz; not the maximum speed at 400 Hz. |
| `PD145` | 100 | 10 % | 2.0% | 0.1–10.0 | 0.1% | Y | | Automatic torque compensation | Adds low-frequency voltage to increase torque. |
| `PD146` | 18 | 18 % | 40% | 0–99 | 1% | Y | | Motor no-load current | No-load current as a percentage of rated motor current. |
| `PD147` | 100 | 10 % | 0.0% | 0.0–10.0 | 0.1% | Y | | Motor slip compensation | Compensates induction-motor slip under load. |
| `PD148` | — | Unsupported by this VFD (CRC-checked `0x81` reply) | Not present in project PDF | | | ? | N | Not present in project PDF | No applicable description is available yet; preserve the raw result. |
| `PD149` | — | Unsupported by this VFD (CRC-checked `0x81` reply) | Not present in project PDF | | | ? | N | Not present in project PDF | No applicable description is available yet; preserve the raw result. |
| `PD150` | 1 | 1: enabled/retained | 1 | 0–1 | 1 | | | Automatic voltage regulation | Stabilizes motor voltage against input-voltage variation. |
| `PD151` | 0 | 0 % | 0% | 0–20 | 1% | | | Automatic energy saving | Reduces voltage under light constant-speed load. |
| `PD152` | 10 | 1 s | 1.0 s | 0.2–25.0 | 0.1 s | | | Fault-restart delay | Delay before an automatic fault restart. |
| `PD153` | 0 | 0: disabled/not retained | 0 | 0–1 | 1 | | | Restart after instantaneous power loss | Allows frequency-track restart after a short power interruption. |
| `PD154` | 5 | 0.5 s | 0.5 s | 0.1–5.0 | 0.1 s | | | Allowable power-loss time | Maximum interruption duration eligible for automatic restart. |
| `PD155` | 0 | 0 | 00 | 00–10 | 1 | | | Number of abnormal restarts | Limits automatic reset/restart attempts; zero disables them. |
| `PD156` |  1000 | 100 % | 100% | 0.0–1000.0 | 0.1% | | | PID proportional constant | Proportional gain of the process PID controller. |
| `PD157` | 50 | 5 s | 5.0 s | 0.1–3600.0 | 0.1 s | | | PID integral time | Integral time of the process PID controller. |
| `PD158` | 0 | 0 s | 0 s | 0.01–10.00 | 0.01 s  | | | PID differential time | Derivative time of the process PID controller. |
| `PD159` | 0 | 0 % | * | 0.0–100.0 | 0.1% | ? | | PID target value | Internally configured PID setpoint. |
| `PD160` | 0 | 0 | 0 | 0–1 | 1 | | | PID target-value source | Selects internal PD159 or external analog PID setpoint. |
| `PD161` | 100 | 100 % | 100% | 0–100 | 1% | | | PID upper limit | Upper PID feedback threshold for a multifunction output. |
| `PD162` | 0 | 0 % | 0% | 0–100 | 1% | | | PID lower limit | Lower PID feedback threshold for a multifunction output. |
| `PD163` | 1 | station 1 | 00 | 0–250 | 1 | Y | | RS-485 station address | Slave address used by the Huanyang serial protocol. |
| `PD164` | 2 | 19200 bit/s | 1 (9600 bit/s) | 0–3 | 1 | Y | | Communication baud rate | Selects serial baud rate. |
| `PD165` | 3 | 8N1 RTU | 0 (8N1 ASCII) | 0–5 | 1 | Y | | Communication data format | Selects ASCII/RTU mode, parity, data bits, and stop bits. |
| `PD166` | 0 | 0 | Not present in project PDF | | | ? | N | Not present in project PDF | No applicable description is available yet; preserve the raw result. |
| `PD167` | 0 | 0 | Not present in project PDF | | | ? | N | Not present in project PDF | No applicable description is available yet; preserve the raw result. |
| `PD168` | 0 | 0 | Not present in project PDF | | | ? | N | Not present in project PDF | No applicable description is available yet; preserve the raw result. |
| `PD169` | — | Unsupported by this VFD (CRC-checked `0x81` reply) | Not present in project PDF | | | ? | N | Not present in project PDF | No applicable description is available yet; preserve the raw result. |
| `PD170` | 0 | inverter temperature | 0 | 0–5 | 1 | | | Additional display item | Selects the optional quantity shown on the front panel. |
| `PD171` | 7 | 7 (0x0007 bit mask) | 0 | 0–15 | 1 | Y | | Display-items enable mask | Enables additional front-panel display quantities. |
| `PD172` | 88 | 88 | 00 | 00–10 | 1 | Y | | Fault clear | Writing 1 clears faults; captured value is outside the manual's documented range. |
| `PD173` |  2550 | 2550 | Not present in project PDF | | | ? | N | Not present in project PDF | No applicable description is available yet; preserve the raw result. |
| `PD174` | 110 | raw 110; likely 11 A, but supplied manual says 1 A/unit | * | | 1 A | ? | | Rated inverter current | Factory/model current rating; documented as read-only. |
| `PD175` | 0 | 0: constant torque | 0 | 0–1 | 1 | | | Inverter load model | Selects constant-torque or fan/pump load model; read-only. |
| `PD176` | 0 | 0: 50 Hz | * | 0–1 | 1 | ? | | Inverter frequency standard | Factory 50/60 Hz region setting; read-only. |
| `PD177` | 91 | 91 (0x005b) | — | | | ? | | Fault record 1 | Stores a historical fault code; decoding requires the matching firmware display-code table. |
| `PD178` | 90 | 90 (0x005a) | — | | | ? | | Fault record 2 | Stores a historical fault code; decoding requires the matching firmware display-code table. |
| `PD179` | 89 | 89 (0x0059) | — | | | ? | | Fault record 3 | Stores a historical fault code; decoding requires the matching firmware display-code table. |
| `PD180` | 91 | 91 (0x005b) | — | | | ? | | Fault record 4 | Stores a historical fault code; decoding requires the matching firmware display-code table. |
| `PD181` | 88 | 88 (0x0058) | * | | | ? | | Software version | Factory software-version code. |
| `PD182` | 17051 | 17051 (0x429b; packed date not decoded) | * | | | ? | | Manufacture date | Factory packed manufacture-date code. |
| `PD183` | 65535 | 65535 (0xffff) | * | | | ? | | Serial number | Factory serial-number field. |
| `PD184` | 20 | 20 | Reserved; none stated | | | ? | R | Reserved | Reserved in the handbook delivered with this VFD. |
| `PD185` | 0 | 0 | Reserved; none stated | | | ? | R | Reserved | Reserved in the handbook delivered with this VFD. |
| `PD186` | 0 | 0 | Reserved; none stated | | | ? | R | Reserved | Reserved in the handbook delivered with this VFD. |
| `PD187` | — | Unsupported by this VFD (CRC-checked `0x81` reply) | Reserved; none stated | | | ? | R | Reserved | Reserved in the handbook delivered with this VFD. |
| `PD188` | — | Unsupported by this VFD (CRC-checked `0x81` reply) | Reserved; none stated | | | ? | R | Reserved | Reserved in the handbook delivered with this VFD. |
| `PD189` | — | Unsupported by this VFD (CRC-checked `0x81` reply) | Reserved; none stated | | | ? | R | Reserved | Reserved in the handbook delivered with this VFD. |
| `PD190` | — | Unsupported by this VFD (CRC-checked `0x81` reply) | Reserved; none stated | | | ? | R | Reserved | Reserved in the handbook delivered with this VFD. |
| `PD191` | — | Unsupported by this VFD (CRC-checked `0x81` reply) | Reserved; none stated | | | ? | R | Reserved | Reserved in the handbook delivered with this VFD. |
| `PD192` | — | Unsupported by this VFD (CRC-checked `0x81` reply) | Reserved; none stated | | | ? | R | Reserved | Reserved in the handbook delivered with this VFD. |
| `PD193` | — | Unsupported by this VFD (CRC-checked `0x81` reply) | Reserved; none stated | | | ? | R | Reserved | Reserved in the handbook delivered with this VFD. |
| `PD194` | — | Unsupported by this VFD (CRC-checked `0x81` reply) | Reserved; none stated | | | ? | R | Reserved | Reserved in the handbook delivered with this VFD. |
| `PD195` | — | Unsupported by this VFD (CRC-checked `0x81` reply) | Reserved; none stated | | | ? | R | Reserved | Reserved in the handbook delivered with this VFD. |
| `PD196` | — | Unsupported by this VFD (CRC-checked `0x81` reply) | Reserved; none stated | | | ? | R | Reserved | Reserved in the handbook delivered with this VFD. |
| `PD197` | — | Unsupported by this VFD (CRC-checked `0x81` reply) | Reserved; none stated | | | ? | R | Reserved | Reserved in the handbook delivered with this VFD. |
| `PD198` | — | Unsupported by this VFD (CRC-checked `0x81` reply) | Reserved; none stated | | | ? | R | Reserved | Reserved in the handbook delivered with this VFD. |
| `PD199` | — | Unsupported by this VFD (CRC-checked `0x81` reply) | Reserved; none stated | | | ? | R | Reserved | Reserved in the handbook delivered with this VFD. |
| `PD200` | 0 | 0 | Reserved; none stated | | | ? | R | Reserved | Reserved in the handbook delivered with this VFD. |
| `PD201` | — | Unsupported by this VFD (CRC-checked `0x81` reply) | Reserved; none stated | | | ? | R | Reserved | Reserved in the handbook delivered with this VFD. |
| `PD202` | — | Unsupported by this VFD (CRC-checked `0x81` reply) | Reserved; none stated | | | ? | R | Reserved | Reserved in the handbook delivered with this VFD. |
| `PD203` | — | Unsupported by this VFD (CRC-checked `0x81` reply) | Reserved; none stated | | | ? | R | Reserved | Reserved in the handbook delivered with this VFD. |
| `PD204` | — | Unsupported by this VFD (CRC-checked `0x81` reply) | Reserved; none stated | | | ? | R | Reserved | Reserved in the handbook delivered with this VFD. |
| `PD205` | — | Unsupported by this VFD (CRC-checked `0x81` reply) | Reserved; none stated | | | ? | R | Reserved | Reserved in the handbook delivered with this VFD. |
| `PD206` | — | Unsupported by this VFD (CRC-checked `0x81` reply) | Reserved; none stated | | | ? | R | Reserved | Reserved in the handbook delivered with this VFD. |
| `PD207` | — | Unsupported by this VFD (CRC-checked `0x81` reply) | Reserved; none stated | | | ? | R | Reserved | Reserved in the handbook delivered with this VFD. |
| `PD208` | — | Unsupported by this VFD (CRC-checked `0x81` reply) | Reserved; none stated | | | ? | R | Reserved | Reserved in the handbook delivered with this VFD. |
| `PD209` | — | Unsupported by this VFD (CRC-checked `0x81` reply) | Reserved; none stated | | | ? | R | Reserved | Reserved in the handbook delivered with this VFD. |
| `PD210` | — | Unsupported by this VFD (CRC-checked `0x81` reply) | Reserved; none stated | | | ? | R | Reserved | Reserved in the handbook delivered with this VFD. |
| `PD211` | — | Unsupported by this VFD (CRC-checked `0x81` reply) | Reserved; none stated | | | ? | R | Reserved | Reserved in the handbook delivered with this VFD. |
| `PD212` | — | Unsupported by this VFD (CRC-checked `0x81` reply) | Reserved; none stated | | | ? | R | Reserved | Reserved in the handbook delivered with this VFD. |
| `PD213` | — | Unsupported by this VFD (CRC-checked `0x81` reply) | Reserved; none stated | | | ? | R | Reserved | Reserved in the handbook delivered with this VFD. |
| `PD214` | — | Unsupported by this VFD (CRC-checked `0x81` reply) | Reserved; none stated | | | ? | R | Reserved | Reserved in the handbook delivered with this VFD. |
| `PD215` | — | Unsupported by this VFD (CRC-checked `0x81` reply) | Reserved; none stated | | | ? | R | Reserved | Reserved in the handbook delivered with this VFD. |
| `PD216` | — | Unsupported by this VFD (CRC-checked `0x81` reply) | Reserved; none stated | | | ? | R | Reserved | Reserved in the handbook delivered with this VFD. |
| `PD217` | — | Unsupported by this VFD (CRC-checked `0x81` reply) | Reserved; none stated | | | ? | R | Reserved | Reserved in the handbook delivered with this VFD. |
| `PD218` | — | Unsupported by this VFD (CRC-checked `0x81` reply) | Reserved; none stated | | | ? | R | Reserved | Reserved in the handbook delivered with this VFD. |
| `PD219` | — | Unsupported by this VFD (CRC-checked `0x81` reply) | Reserved; none stated | | | ? | R | Reserved | Reserved in the handbook delivered with this VFD. |
| `PD220` | — | Unsupported by this VFD (CRC-checked `0x81` reply) | Reserved; none stated | | | ? | R | Reserved | Reserved in the handbook delivered with this VFD. |
| `PD221` | — | Unsupported by this VFD (CRC-checked `0x81` reply) | Reserved; none stated | | | ? | R | Reserved | Reserved in the handbook delivered with this VFD. |
| `PD222` | — | Unsupported by this VFD (CRC-checked `0x81` reply) | Reserved; none stated | | | ? | R | Reserved | Reserved in the handbook delivered with this VFD. |
| `PD223` | — | Unsupported by this VFD (CRC-checked `0x81` reply) | Reserved; none stated | | | ? | R | Reserved | Reserved in the handbook delivered with this VFD. |
| `PD224` | — | Unsupported by this VFD (CRC-checked `0x81` reply) | Reserved; none stated | | | ? | R | Reserved | Reserved in the handbook delivered with this VFD. |
| `PD225` | — | Unsupported by this VFD (CRC-checked `0x81` reply) | Reserved; none stated | | | ? | R | Reserved | Reserved in the handbook delivered with this VFD. |
| `PD226` | — | Unsupported by this VFD (CRC-checked `0x81` reply) | Reserved; none stated | | | ? | R | Reserved | Reserved in the handbook delivered with this VFD. |
| `PD227` | — | Unsupported by this VFD (CRC-checked `0x81` reply) | Reserved; none stated | | | ? | R | Reserved | Reserved in the handbook delivered with this VFD. |
| `PD228` | — | Unsupported by this VFD (CRC-checked `0x81` reply) | Reserved; none stated | | | ? | R | Reserved | Reserved in the handbook delivered with this VFD. |
| `PD229` | — | Unsupported by this VFD (CRC-checked `0x81` reply) | Reserved; none stated | | | ? | R | Reserved | Reserved in the handbook delivered with this VFD. |
| `PD230` | — | Unsupported by this VFD (CRC-checked `0x81` reply) | Reserved; none stated | | | ? | R | Reserved | Reserved in the handbook delivered with this VFD. |
| `PD231` | — | Unsupported by this VFD (CRC-checked `0x81` reply) | Reserved; none stated | | | ? | R | Reserved | Reserved in the handbook delivered with this VFD. |
| `PD232` | — | Unsupported by this VFD (CRC-checked `0x81` reply) | Reserved; none stated | | | ? | R | Reserved | Reserved in the handbook delivered with this VFD. |
| `PD233` | — | Unsupported by this VFD (CRC-checked `0x81` reply) | Reserved; none stated | | | ? | R | Reserved | Reserved in the handbook delivered with this VFD. |
| `PD234` | — | Unsupported by this VFD (CRC-checked `0x81` reply) | Reserved; none stated | | | ? | R | Reserved | Reserved in the handbook delivered with this VFD. |
| `PD235` | — | Unsupported by this VFD (CRC-checked `0x81` reply) | Reserved; none stated | | | ? | R | Reserved | Reserved in the handbook delivered with this VFD. |
| `PD236` | — | Unsupported by this VFD (CRC-checked `0x81` reply) | Reserved; none stated | | | ? | R | Reserved | Reserved in the handbook delivered with this VFD. |
| `PD237` | — | Unsupported by this VFD (CRC-checked `0x81` reply) | Reserved; none stated | | | ? | R | Reserved | Reserved in the handbook delivered with this VFD. |
| `PD238` | — | Unsupported by this VFD (CRC-checked `0x81` reply) | Reserved; none stated | | | ? | R | Reserved | Reserved in the handbook delivered with this VFD. |
| `PD239` | — | Unsupported by this VFD (CRC-checked `0x81` reply) | Reserved; none stated | | | ? | R | Reserved | Reserved in the handbook delivered with this VFD. |
| `PD240` | — | Unsupported by this VFD (CRC-checked `0x81` reply) | Reserved; none stated | | | ? | R | Reserved | Reserved in the handbook delivered with this VFD. |
| `PD241` | — | Unsupported by this VFD (CRC-checked `0x81` reply) | Reserved; none stated | | | ? | R | Reserved | Reserved in the handbook delivered with this VFD. |
| `PD242` | — | Unsupported by this VFD (CRC-checked `0x81` reply) | Reserved; none stated | | | ? | R | Reserved | Reserved in the handbook delivered with this VFD. |
| `PD243` | — | Unsupported by this VFD (CRC-checked `0x81` reply) | Reserved; none stated | | | ? | R | Reserved | Reserved in the handbook delivered with this VFD. |
| `PD244` | — | Unsupported by this VFD (CRC-checked `0x81` reply) | Reserved; none stated | | | ? | R | Reserved | Reserved in the handbook delivered with this VFD. |
| `PD245` | — | Unsupported by this VFD (CRC-checked `0x81` reply) | Reserved; none stated | | | ? | R | Reserved | Reserved in the handbook delivered with this VFD. |
| `PD246` | — | Unsupported by this VFD (CRC-checked `0x81` reply) | Reserved; none stated | | | ? | R | Reserved | Reserved in the handbook delivered with this VFD. |
| `PD247` | — | Unsupported by this VFD (CRC-checked `0x81` reply) | Reserved; none stated | | | ? | R | Reserved | Reserved in the handbook delivered with this VFD. |
| `PD248` | — | Unsupported by this VFD (CRC-checked `0x81` reply) | Reserved; none stated | | | ? | R | Reserved | Reserved in the handbook delivered with this VFD. |
| `PD249` | — | Unsupported by this VFD (CRC-checked `0x81` reply) | Reserved; none stated | | | ? | R | Reserved | Reserved in the handbook delivered with this VFD. |
| `PD250` | — | Unsupported by this VFD (CRC-checked `0x81` reply) | Reserved; none stated | | | ? | R | Reserved | Reserved in the handbook delivered with this VFD. |

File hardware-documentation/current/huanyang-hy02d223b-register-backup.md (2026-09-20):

# Huanyang HY02D223B register backup

Captured `2026-09-19T14:10:14.449665+00:00` through `/dev/ttyUSB0` at
19,200 bit/s, 8N1, station 1.

The capture program transmitted only Huanyang function `0x01` (read
parameter). The raw, CRC-checked request and response frames are preserved in
[`data/huanyang-hy02d223b-registers-pd000-pd250-2026-09-19.json`](data/huanyang-hy02d223b-registers-pd000-pd250-2026-09-19.json).

The capture covers `PD000`–`PD250`: 170 registers returned values, 81 returned
CRC-valid unsupported replies, and none ended in errors. The complete generated
record is in the
[`Huanyang HY02D223B register table`](huanyang-hy02d223b-register-backup-table.md).

Decoded values and descriptions initially came from
[`datasheets/huanyang-hy02d223b-manual.pdf`](datasheets/huanyang-hy02d223b-manual.pdf).
That project PDF is not the same revision as the handbook delivered with this
VFD. Owner-confirmed handbook corrections, including its documented set ranges
and setting units, take precedence; untranscribed conflicts are marked pending
rather than guessed.

In the table's factory-setting column, `*` retains the manual's notation for a
model- or application-specific value; an em dash means the manual gives no
fixed initial value. A blank set range or unit means that the delivered handbook
does not document one in the transcribed material.

[1] Modified: blank means the captured value equals the numeric factory
setting; `Y` (yes) means it differs; `?` means comparison is not possible from
this capture/manual.

[2] Reserved: `R` (reserved) means explicitly marked reserved in the delivered handbook;
`N` (not present) means the parameter is not present in the project PDF; blank means it is
documented and not marked reserved.

## Important recovered settings

- Run commands and frequency both come from communications (`PD001=2`,
  `PD002=2`).
- Serial settings are station 1, 19,200 bit/s, 8N1 RTU (`PD163=1`, `PD164=2`,
  `PD165=3`).
- Base and maximum frequency are both 400 Hz (`PD004`, `PD005`).
- The lower operating limit is 13.40 Hz (`PD011`), corresponding to about
  804 rpm with `PD144=3000 rpm at 50 Hz`.
- Motor data are 220 V, 10.0 A, 2 poles and 3000 rpm at 50 Hz
  (`PD141`–`PD144`). The 10.0 A setting conflicts with the spindle's informal
  paper value of 6 A and must be resolved before commissioning.
- Reverse rotation is forbidden (`PD023=0`) and the panel STOP key is enabled
  (`PD024=1`).
- One auxiliary pump is configured (`PD130=1`), and `PD133`–`PD139` contain
  non-default pump/sleep timings and thresholds. The coolant-pump conductor
  appears to be on `FA(MB)` or `FC(MB)`; verify it physically before changing
  anything.
- No automatic abnormal restart is configured (`PD155=0`), and restart after
  instantaneous power loss is disabled (`PD153=0`).
- The delivered handbook marks `PD184`–`PD250` reserved. The VFD nevertheless
  returned `PD184=20`, `PD185=0`, `PD186=0` and `PD200=0`; preserve these values
  without assigning a meaning or writing them. Apart from `PD200`, every query
  from `PD187`–`PD250` returned a CRC-valid unsupported reply.

## Capture and rendering tools

[`tools/read-huanyang-vfd.py`](tools/read-huanyang-vfd.py) is deliberately
read-only: its request builder contains only function `0x01`. Do not replace it
with `hy_vfd --regdump` for forensic captures, because the normal `hy_vfd` loop
subsequently transmits control and frequency commands.

Regenerate the default Markdown table with:

```console
python3 hardware-documentation/current/tools/render-huanyang-register-table.py \
  hardware-documentation/current/data/huanyang-hy02d223b-registers-pd000-pd250-2026-09-19.json \
  hardware-documentation/current/huanyang-hy02d223b-register-backup-table.md
```

Use an output name ending in `.csv`, or pass `--format csv`, to render the same
columns and rows as CSV.

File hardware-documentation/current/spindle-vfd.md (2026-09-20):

# Spindle, Huanyang VFD, and coolant

The inverter is a Huanyang `HY02D223B`; the installed spindle is the 2.2 kW
water-cooled ER20 unit described in [`inventory.md`](inventory.md).

## Control path and coolant evidence

- Legacy `hy_vfd` used `/dev/ttyUSB0`, 19,200 baud, 8N1, address 1.
- The old UI defaulted to 800 rpm and allowed up to 24,000 rpm. This does not
  establish a safe minimum speed.
- The BerryBase adapter contains a CH340C and MAX485 ESA and is not galvanically
  isolated. Its exposed screw terminal is differential RS-485, not TTL UART.
- Mesa serial channel 0 supports two-wire low-speed RS-485, but TB4 is not one
  of the galvanically isolated field circuits and PktUART is not a
  `/dev/ttyUSB*` device. It is not a wire-for-wire or software-compatible
  replacement for the existing adapter.
- Ebyte `E810-R12` is a candidate transparent isolated RS-485 hub, not a
  confirmed purchase. `CH1` and `CH2` are duplicate branches, not RX/TX.
- The old schematic omits the coolant pump. Physical observation places it on
  `FA(MB)` or, less likely, `FC(MB)`; verify the terminal.
- Available terminal documents conflict: one table names `FA(MB)`, `FB(MA)`,
  `FC(MA)`, while a diagram orders `FC(MA)`, `FA(MB)`, `FB(MA)`. They likely
  describe one changeover multifunction relay, but continuity and labels must
  confirm that inference.
- The capture has `PD130=1` and non-default pump/sleep settings in
  `PD133`–`PD139`, while `PD050`–`PD053` do not select auxiliary-pump function
  25. Trace how the pump is actually switched.
- Verify contact type and rating; use a suitable interposing relay/contactor if
  needed. A future coolant-flow fault should inhibit spindle operation.

## Read-only VFD parameter backup

The `PD000`–`PD250` capture issued no write, run, stop, or frequency command.
Of 251 queries, 170 returned values, 81 returned CRC-valid unsupported-function
responses, and none ended in error.

- [`huanyang-hy02d223b-register-backup.md`](huanyang-hy02d223b-register-backup.md)
  describes the capture and its important recovered settings.
- [`huanyang-hy02d223b-register-backup-table.md`](huanyang-hy02d223b-register-backup-table.md)
  is the generated human-readable table.
- [`data/huanyang-hy02d223b-registers-pd000-pd250-2026-09-19.json`](data/huanyang-hy02d223b-registers-pd000-pd250-2026-09-19.json)
  preserves every raw request and response.
- [`tools/read-huanyang-vfd.py`](tools/read-huanyang-vfd.py) constructs only
  Huanyang function `0x01` read requests.
- [`tools/render-huanyang-register-table.py`](tools/render-huanyang-register-table.py)
  regenerates the table from JSON as Markdown by default or CSV on request.

Recovered values include communications as both command and frequency source,
400 Hz base/maximum, 13.40 Hz lower limit, reverse forbidden, and motor data of
220 V, 10.0 A, two poles, and 3000 rpm at 50 Hz. The captured 10.0 A conflicts
with the spindle paper's 6 A. Resolve it before commissioning; do not change the
VFD based on either unverified value.

The project PDF is not the same revision as the delivered handbook. The
delivered copy marks `PD035`–`PD040`, `PD067`–`PD069`, `PD079`, and
`PD184`–`PD250` reserved; documents `PD089`–`PD100` and `PD109`–`PD119`; and
describes `PD081`–`PD085` differently. Those observations take precedence in
the generated table. Untranscribed conflicts remain pending.

Although the handbook reserves `PD184`–`PD250`, the VFD returned `PD184=20`,
`PD185=0`, `PD186=0`, and `PD200=0`. Preserve them as unexplained forensic
observations and never assign them a meaning or write them.

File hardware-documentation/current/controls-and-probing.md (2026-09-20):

# Probing, pendant, and operator controls

## Automatic relative tool-length offset

The legacy setup used `M600` to make the next tool the job reference. Its
remapped `M6` stopped spindle/coolant, raised Z, moved to the fixed sensor,
performed coarse and fine `G38.2` probes, calculated a relative length, applied
`G43.1`, and returned to the corrected prior position.

Recovered values are **Legacy-derived**:

| Item | Value |
| --- | ---: |
| Coarse sensor X/Y | X 62 mm, Y 489 mm |
| Fine sensor X/Y | X 77 mm, Y 489 mm |
| Safe/travel Z | 0 mm |
| Fast approach / lowest probe Z | −55 mm / −129 mm |
| Retract | 1 mm |
| Coarse / fine feed | 180 / 10 mm/min |
| Manual tool-change X/Y | X 120 mm, Y 50 mm |

Revalidate every coordinate. Wrong sensor position or polarity can drive the
tool into the table.

## Workpiece touch-off

Legacy `probe-touch-off.ngc` used `G38.2` on X, Y, or Z and updated the active
work coordinate system with `G10 L2`. Pendant commands used a 10 mm maximum
move at 15 mm/min, 10.00 mm X/Y plate thickness, and 26.40 mm Z thickness.
Verify the physical plate dimensions before reuse.

The fixed sensor and removable probe both fed `motion.probe-input`; current
wiring and HAL must make selection, combination, and fault behavior explicit.

## Wireless pendant

The installed label reads `MACH3`, `WHB04B-6`, `QC01`, `2017-05`, correcting
an earlier `WHB08B-4:4` transcription. The receiver identifies as
`10ce:eb93`, manufacturer `KTURT.LTD`, matching LinuxCNC's
`xhc-whb04b-6` component.

A standalone live probe could not open the receiver because the desktop user
lacked USB/hidraw write access and no matching udev rule was installed. Identity
is confirmed; live buttons, selectors, and wheel reports remain to be tested.
The upstream protocol notes also retain checksum/CRC uncertainty for some
button packets; basic pendant support still exists.

The commissioning profile supplies a least-privilege `uaccess` rule at
[`../../config/frida-mesa/udev/70-xhc-whb04b-6.rules`](../../config/frida-mesa/udev/70-xhc-whb04b-6.rules).

## Front-panel switches

| Switch | Stated function | Details still needed |
| --- | --- | --- |
| Monitor | Monitor power | Voltage, fuse, mains versus low-voltage switching |
| Vacuum relay | 230 V vacuum relay | Relay/contactor, coil, contacts, controlled load |
| Auxiliary power | 5 V/12 V peripherals | Supply, rail currents, fusing, consumers |
| Spindle power | VFD/spindle power | Direct mains switch versus contactor; interlocks |
| Stepper-driver power | Drive supply | Switching, discharge time, current `U1` behavior |
| Vacuum pump | Vacuum pump | Model, voltage/current, distinction from vacuum relay |

Future schematics must show these manual controls even when LinuxCNC does not
monitor them.

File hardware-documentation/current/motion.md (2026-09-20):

# Motion, homing, limits, and sensors

All values recovered from the old configuration are **Legacy-derived** until
commissioning proves them on the current machine.

## Stepper-drive settings recovered from legacy notes

| Setting | X | Y | Z |
| --- | ---: | ---: | ---: |
| Peak current | 3.3 A | 3.3 A | 3.5 A |
| Idle current / timeout | 50% / 2,000 ms | 50% / 2,000 ms | 50% / 2,000 ms |
| Electrical damping | 1,000 | 1,000 | 1,000 |
| Alarm polarity | Active low | Active low | Active low |
| Active step edge / direction definition | Rising / Low | Rising / Low | Rising / Low |
| Phase-error / sensorless-stall detection | Enabled | Enabled | Enabled |
| Pulse smoother | Disabled | Disabled | Disabled |
| ENA reset / high-active ENA | Enabled | Enabled | Enabled |

Legacy notes say pulse smoothing caused sporadic lost steps. They also record a
move from a 24 V toroidal supply to HWS1000-48, which reduced resonance; that
supply was later replaced by the installed fanless 56 VDC `U1`.

## Machine coordinate envelope and homing

These are old software limits, not verified mechanical measurements.

| Axis | Minimum | Maximum | Span | Home | Offset | Sensor/direction | Max velocity | Max acceleration |
| --- | ---: | ---: | ---: | ---: | ---: | --- | ---: | ---: |
| X | 61 mm | 571 mm | 510 mm | 62 mm | 60 mm | X−, negative | 35 mm/s | 85 mm/s² |
| Y | 14 mm | 491 mm | 477 mm | 490 mm | 492 mm | Y+, positive | 35 mm/s | 85 mm/s² |
| Z | −130 mm | 0.5 mm | 130.5 mm | 0 mm | 1 mm | Z+, positive/up | 35 mm/s | 85 mm/s² |

Legacy scale is 80 steps/mm for X/Y and −80 steps/mm for Z. Z homes first
(`HOME_SEQUENCE=0`), followed by X and Y together (`HOME_SEQUENCE=1`).
Re-establish direction, scale, usable travel, and braking distance before using
these limits.

```text
                         Y+ / home near 490 / limit 491
                         ^
 X- / home near 62       +------------------------------> X+
 X limit 61                    510 mm span                  X limit 571

 Z+ / home 0 / upper limit 0.5
 ^
 | 130.5 mm span
 v
 Z- / lower limit -130
```

## Limit and home sensors

| Number | Label | Confirmed position/function |
| ---: | --- | --- |
| 4 | `X-` | X minimum |
| 5 | `XH` | Dedicated X home |
| 6 | `X+` | X maximum |
| 3 | `Y+` | Y maximum |
| Not recorded | `YH` | Dedicated Y home |
| Not recorded | `Y-` | Y minimum |
| 8 | `Z-` | Z minimum |
| 7 | `Z+` | Z maximum |

There is no separate Z-home sensor. The active legacy HAL ignored `XH` and
`YH`, using X−, Y+, and Z+ as home signals. Test positions, polarity, and the
desired sequence before using dedicated X/Y home sensors; decide explicitly
whether Z+ remains both home and upper limit.

## Sensor interface migration

The old Panther interface needed a level-protection workaround because the NPN
sensors required more voltage than the BeagleBone input tolerated. Do not copy
that circuit merely because it appears in the legacy schematic.

The 7I95T isolated inputs accept 4–36 VDC and positive or negative commons for
sourcing or sinking applications. Design and test the exact common, polarity,
sensor supply, fuse, shielding, and allocation before connection.

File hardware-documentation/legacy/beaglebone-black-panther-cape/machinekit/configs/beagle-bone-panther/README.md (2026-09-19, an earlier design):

# Introduction

This repository contains MachineKit (linuxcnc) configuration files for an other selfmade CNC machine.

She calls her is Frida!

## Key pparameters:

* Jog dial: XHC-WHB04B-6, a wireless 6 axis jog dial
* Huangyang Inverter: hy_vfd component
* Hardware: Beagle Bone Black with Necitec's Panter cape
* QtQuickVcp: configured
* Debian Image: Linux beaglebone 4.4.155-ti-rt-r150 #1 SMP PREEMPT RT Tue Dec 4 20:08:09 UTC 2018 armv7l GNU/Linux
* Circuit diagram available (Killcad)

## Installation

```
git clone https://github.com/rubienr/bbb-linuxcnc-config.git
bbb-linuxcnc-config/machinekit/configs/beagle-bone-panther/run.py
```

## BBB Device Tree

If necesary the 

## References
[BeagleBone_Debian_Image_Migration](https://elinux.org/Beagleboard:BeagleBone_Debian_Image_Migration)
[manage capes](http://www.raspberry-pi-geek.de/Magazin/2015/01/BeagleBone-Black-Capes-verwalten/\(offset\)/2)

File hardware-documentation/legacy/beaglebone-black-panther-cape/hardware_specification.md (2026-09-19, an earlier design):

# Introduction

This page breafly introcudes the hardware configuration of the CNC milling machine.
* 3-Axis CNC
* 1.8°, 3A stepper
* [8.2A Leadshine AM882HN stepper driver](http://www.leadshine.com/UploadFile/Down/AM882m.pdf)
* [Beagle Bone Black](https://beagleboard.org/black)
* Software: [Machinekit](https://github.com/rubienr/machinekit) (former LinuxCNC)

# Hardware Configuration
## Power Supply (Stepper/Driver)
| Config ID | Config Notes | Type | Supply Voltage [V] | Max. Current [A] | Max. Power [W] |
| --- | --- | --- | --- | --- | --- |
| ID-PWR-24  | C | transformer, torus | 24 | 16 | 380 |
| ID-PWR-48  | C | TDK Lamda, HWS1000-48 | 48 | 23 | 1000 |

## Motor Specification
| Axis | Config ID | Motor | Deree/Step [°] | Current [A] | Voltage [V] | Inductance [mH] | Resistance [Ohm] |
| --- | --- | --- | --- | --- | --- | --- | --- |
| X | ID-MX1 | StepSyn 103H7126-0703 | 1.8 | 3 | | | |
| Y | ID-MY1 | StepSyn 103H7126-0703 | 1.8 | 3 | | | |
| Z | ID-MZ1 | Vexta C1824-9212H | 1.8 | 3.27 | 3.66 | | |

## Stepper driver (Leadshine AM882HN)
### Electrical Configuration
| Axis | Config ID | Config Notes | Peak Current [A] | Idle Current [%] | Idle Timeout [ms] | Electrical Damping | 
| ---  | --- |--- | --- | --- | --- | --- |
| X | ID-DR-EL-X1 | A | 3.3 | 50 | 2000 | 1000 |
| Y | ID-DR-EL-Y1 | A | 3.3 | 50 | 2000 | 1000 |
| Z | ID-DR-EL-Z1 | A | 3.5 | 50 | 2000 | 1000 |

### Signal  Configuration
| Axis | Config ID | Config. Notes | Alarm Signal | Active Edge | Direction Def. |
| ---- | --- | --- | --- | --- | --- |
| X | ID-DR-SIG-X1 | A | low | *rising* | low |
| Y | ID-DR-SIG-Y1 | A | low | *rising* | low |
| Z | ID-DR-SIG-Z1 | A | low | *rising* | low |

## Feature Configuration 
| Axis | Config ID | Config. Notes | Phase Error Detection | Sensorless Stall Detection | Pulse Smoother | ENA Reset | High Active ENA |
| ---- | --- | --- | --- | --- | --- | --- | --- |
| X | ID-DR-FE-X1 | A, B | enabled | enabled | enabled | enabled | enabled |
| Y | ID-DR-FE-Y1 | A, B | enabled | enabled | enabled | enabled | enabled |  
| Z | ID-DR-FE-Z1 | A, B | enabled | enabled | enabled | enabled | enabled |
| X | ID-DR-FE-X2 | A | enabled | enabled | **disabled** | enabled | enabled |
| Y | ID-DR-FE-Y2 | A | enabled | enabled | **disabled** | enabled | enabled |
| Z | ID-DR-FE-Z2 | A | enabled | enabled | **disabled** | enabled | enabled |

### Current Controller
| Axis | Config ID | Config Notes | Kp | Ki |
| ---- | --- | --- | ---- | ---- |
| X | ID-DR-CC-X1 | A | x | x |
| X | ID-DR-CC-Y1 | A | 6500 | 1000 |
| Z | ID-DR-CC-Z1 | A | 6500 | 1000 |

### Damping Configuration
| Axis | Config ID | Config Notes | 1st Resonance Amp1 | 1st Resonance Amp2 | 2nd Resonance Amp1 | 2nd Resonance Amp2 | 3rd Resonance Amp1 | 3rd Resonance Amp2 |
| ---- | --- | --- | --- | --- | --- | --- | --- | --- |
| X | ID-DR-DC-X1 | A | 7725  | 829  | 1460  | 1006 | 123 | 121 |
| Y | ID-DR-DC-Y1 | A | 11000 | 857  | 10000 | 900  | 122 | 119 |
| Z | ID-DR-DC-Z1 | A | 5003  | 888  | 1460  | 632  | 128 | 128 |
| X | ID-DR-DC-X2 | D | 0 | 0 | 0 | 0 | 128 | 128 |
| Y | ID-DR-DC-Y2 | D | 0 | 0 | 0 | 0 | 128 | 128 |
| Z | ID-DR-DC-Z2 | D | 0 | 0 | 0 | 0 | 128 | 128 |

### Configuration Notes
| Config. Note | Notes |
| --- | --- |
| A | Initial Configuration using power supply as described in ID-PWR-24. |
| B | Faced issue with sporadic lost steps when Pulse Smoother was enabled (input pulse ripple filter), thus disabled. | 
| C | Replaced rather weak transformer. The higher voltage decreases the coil saturation time, thus increases the stepper speed. |
| D | With power supply as described in ID-PWR-48, the stepper resonance issue has almost disappeared. Thus default anti-resonance values as stated in the driver documentation are fine. |

## Total Configuration
| Motor Config Set | Power Supply | Driver Config Set | Notes | 
| --- | --- | ---| ----- |
| ID-M[XYZ]1 | ID-PWR-48 | ID-DR-{EL,SIG,FE,CC,DC}-[XYZ]1 | Initial configuration but issue with loosing steps. See also configuraton note A |
| ID-M[XYZ]1 | ID-PWR-48 | ID-DR-{EL,SIG,CC,DC}-[XYZ]1, ID-DR-FE-[XYZ]**2** | Normal Performance, not loosing steps. |

# Notes
* For proper step speed limits consider reading the Stepper Information reference.

# References
* [Stepper Information: Inductance/Voltage/Current/Saturation delay ...](http://linuxcnc.org/docs/html/integrator/steppers.html)
* [8.2A Leadshine AM882HN stepper driver](http://www.leadshine.com/UploadFile/Down/AM882m.pdf)
* [Beagle Bone Black](https://beagleboard.org/black)
* [BBB: Connecting Battery](https://www.element14.com/community/community/designcenter/single-board-computers/next-gen_beaglebone/blog/2013/08/10/bbb--rechargeable-on-board-battery-system)
* [Machinecit source repository](https://github.com/rubienr/machinekit)

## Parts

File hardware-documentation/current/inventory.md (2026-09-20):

# Current hardware inventory

Status terms are defined in [`README.md`](README.md). Unknown model suffixes and
ratings remain open work in [`TODO.md`](TODO.md).

## Known hardware

| Function | Manufacturer/model | Known details | Status |
| --- | --- | --- | --- |
| Motion controller | Mesa 7I95T | Ethernet; six differential step/dir channels, encoder inputs, 24 isolated field inputs, six isolated outputs; regulated 5 V card supply | Confirmed |
| Stepper drives X/Y/Z | Leadshine AM882HN | Three drives; legacy symbols say `AM882H-SFQ`; 20–80 VDC class, up to 8.2 A peak | Legacy documentation; photograph suffixes |
| X/Y motors | Sanyo Denki StepSyn `103H7126-0703` | 1.8 degrees/step, recorded as 3 A; drawing says `103H7126-07G3` | Legacy-derived; verify nameplates |
| Z motor | Vexta `C1824-9212H` | 1.8 degrees/step, 3.27 A, 3.66 V; drawing appears to say `C8124-9212H` | Legacy-derived; verify nameplate |
| `U1`, drive supply | Unknown | Fanless replacement marked 230 VAC, 5 A input and 56 VDC output; replaced the documented HWS1000-48 | Ratings confirmed; model and DC output rating to verify |
| `U2`, auxiliary supply | Glendale Electronic Components `GE-003` | 230 VAC input; +5 VDC/2 A, −5 VDC/1 A, +12 VDC/2.5 A | Marking confirmed; pinout and consumers to verify |
| Inverter | Huanyang `HY02D223B` | 2.2 kW, 220 V class; capture confirms 19,200 baud, 8N1 RTU, address 1 | Confirmed |
| Legacy VFD interface | BerryBase `USB-RS485`, ASIN [`B09KV6TG3K`](https://www.amazon.de/dp/B09KV6TG3K) | CH340C and observed MAX485 ESA; two-wire RS-485; no galvanic isolation; one failed unit | Confirmed legacy hardware; replacement undecided |
| Spindle | Unidentified Chinese 2.2 kW ER20 water-cooled spindle | 220 VAC, paper states 6 A, 0–400 Hz, 10,000–24,000 rpm, 80 mm body, about 250 mm long, 4.9 kg | Physical description and paper confirmed; maker/model unknown |
| Limit/home sensors | Eight `LJ12A3-4-Z/AX` | NPN normally closed, nominal 4 mm; X/Y each min, home, max; Z min/max | Count, positions, labels confirmed; electrical behavior and destinations to test |
| Pendant | XHC `WHB04B-6` | Label: `MACH3`, `WHB04B-6`, `QC01`, `2017-05`; receiver `10ce:eb93`, `KTURT.LTD` | Identity confirmed; live packet test remains |
| Fixed tool-height sensor | Unknown | Automatic relative tool-length measurement | Function confirmed; details unknown |
| Workpiece probe/plate | Unknown | X/Y/Z workpiece touch-off | Function confirmed; dimensions and wiring to verify |
| Water pump | Unknown | Spindle coolant; believed on VFD `FA(MB)` or possibly `FC(MB)` | Terminal and ratings to verify |

## Spindle paper specification

The spindle arrived with a typewritten sheet, not a credible manufacturer
datasheet. Preserve it as evidence, including its contradictions:

| Paper entry | Recorded value | Interpretation |
| --- | --- | --- |
| Description | “2.2kw ER20 square water cooled spindle motor engraving milling grind” | Installed body is cylindrical, not square |
| Material | Stainless steel | Pending inspection |
| Power / voltage / current | 2.2 kW / 220 VAC / 6 A | Verify current against nameplate and VFD settings |
| Frequency / speed | 0–400 Hz / 10,000–24,000 rpm | Does not establish safe operation near 0 Hz |
| Cooling | “air-cooled” | Wrong; installed spindle is water-cooled |
| Runout / taper precision | at most 0.01 mm / 0.005 mm | Measurement conditions unknown |
| Bearings | Four ceramic bearings; grease lubrication | Exact bearing type unknown |
| Collet / weight | ER20 / 4.9 kg | Accepted as stated |

Program the VFD only from verified motor data. Confirm rated current,
frequency, safe minimum speed, pole count/rated rpm, ramps, braking, and coolant
requirements first.

## Datasheets and manuals

| File | Scope and caveat |
| --- | --- |
| [`datasheets/mesa-7i95t-manual.pdf`](datasheets/mesa-7i95t-manual.pdf) | Manufacturer manual for the installed controller |
| [`datasheets/ebyte-e810-r1x-user-manual-v1.1.pdf`](datasheets/ebyte-e810-r1x-user-manual-v1.1.pdf) | Manufacturer manual; E810-R12 is only a candidate isolation stage |
| [`datasheets/huanyang-hy-series-instruction-67-numbered-pages.pdf`](datasheets/huanyang-hy-series-instruction-67-numbered-pages.pdf) | Strong matching-handbook candidate with corrected reserved ranges and terminal aliases |
| [`datasheets/huanyang-hy-series-instruction-67-numbered-pages-ocr.pdf`](datasheets/huanyang-hy-series-instruction-67-numbered-pages-ocr.pdf) | Searchable derivative; check OCR against scan for safety-relevant use |
| [`datasheets/huanyang-hy-series-instruction-67-numbered-pages-ocr.txt`](datasheets/huanyang-hy-series-instruction-67-numbered-pages-ocr.txt) | Search sidecar, not authoritative |
| [`datasheets/huanyang-hy-series-0.75kw-2.2kw-official-2024.pdf`](datasheets/huanyang-hy-series-0.75kw-2.2kw-official-2024.pdf) | Official one-page brochure, not an operating handbook |
| [`datasheets/huanyang-hy02d223b-manual.pdf`](datasheets/huanyang-hy02d223b-manual.pdf) | Searchable family manual explicitly containing this model; revision differs from delivered handbook |
| [`datasheets/leadshine-am882-manual.pdf`](datasheets/leadshine-am882-manual.pdf) | Third-party-preserved AM882 manual; original link is dead |
| [`datasheets/lj12a3-4-z-ax-reference.pdf`](datasheets/lj12a3-4-z-ax-reference.pdf) | Third-party generic sensor reference; installed maker unknown |
| [`datasheets/tdk-lambda-hws1000-installation-manual.pdf`](datasheets/tdk-lambda-hws1000-installation-manual.pdf) | Former supply only; not the installed replacement |
| [`datasheets/sanyo-denki-sanmotion-f2-catalog.pdf`](datasheets/sanyo-denki-sanmotion-f2-catalog.pdf) | Family catalog; does not resolve `0703` versus `07G3` |

Do not substitute a family manual for the actual nameplate when selecting
voltage, current, protection, or VFD parameters.

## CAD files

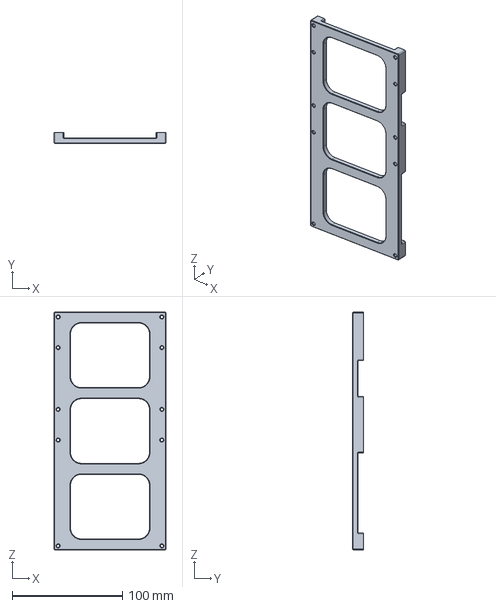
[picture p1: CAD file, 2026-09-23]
hardware-documentation/current/cad/mesa-card-bracket.FCStd
101.6 x 10.0 x 215.9 mm

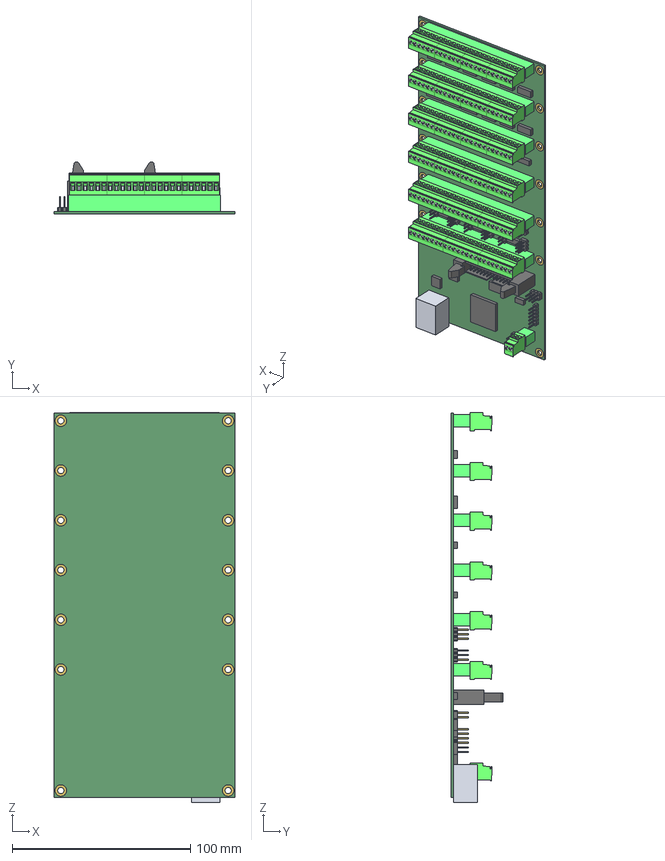
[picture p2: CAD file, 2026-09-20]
hardware-documentation/current/mechanical/mesa-7i95t/7i95.step
101.6 x 29.5 x 219.0 mm
7i95
Plug_2Pin
Plug_6Pin x 16
Plug_8Pin x 6

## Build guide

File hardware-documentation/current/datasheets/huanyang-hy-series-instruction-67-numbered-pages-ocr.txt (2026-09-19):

(' 2006068887

o —
Y,

Huanyang Inverter

-
Add : rm19,Block D,10/F,Wongking Ind Bldg,2 Tai
Yau St,San Po Kong,Kowloon,Hongkong

Huanyang Inverter

Instruction

HONG KONG Y&F GROUP LIMITED

[OCR skipped on page(s) 2]
01

! ’ As THE USE OF MANUAL

| . Introduction

Thank you for purchasing and using the general-purpose inverter of HY series of multi-functions
and high performance.

Please read carefully the operation manual before putting the inverter to use so as to correctly
install and operate the inverter, give full play to its functions and ensure the safety. Please keep the
operation manual handy for future reference, maintenance, inspection and repair.

Due to the inverter of a kind of electrical and electronic product it must be installed , tested and
adjusted with parameters by specialized engineering persons of motors.

The marks of and other symbols in the manual remind you of the safety and
prevention cautions during the handling, installation, running and inspection. Please follow these
instructions to make sure the safe use of the inverter. In case of any doubt please contact our local
agent for consultation. Our professional persons are willing and ready to serve you.

The manual is subject to change without notice.

N Danger indicates wrong use may kill or injure people.
A Caution indicates wrong use may damage the inverter or mechanical system.

® Be sure to turn off the input power supply before wiring.

® Do not touch any internal electrical circuit or component when the charging lamp is still on after the
AC power supply is disconnected, which means the inverter still has high voltage inside and it is very
dangerous.

® Do not check components and signals on the circuit boards during the operation.

® Do not dissemble or modify any internal connecting cord, wiring or component of the inverter by
yourself.

® Be sure to make correct ground connection of the earth terminal of the inverter.

® Never remodel it or exchange control boards and components by yourself. It may expose you to an
electrical shock or explosion, etc.

® Do not make any voltage-withstanding test with any component inside the inverter. These semi-
conductor parts are subject to the damage of high voltage.

® Never connect the AC main circuit power supply to the output terminals U.-VW of the inverter.

® The main electric circuit boards of CMOS and IC of the inverter are subject to the effect and damage
of static electricity. Don't touch the main circuit boards.

® Installation, testing and maintenance must be performed by qualified professional personnel.

® The inverter should be discarded as industrial waste. It is forbidden to burn it.

B

1. Checks upon Delivery

The inverter has been strictly and well packed before ex-work. In consideration of various factors
during the transportation special attention should be paid to the following points before the
assembly and installation. If there is anything abnormal please notify the dealer or the relevant
people of our company.

® Check ifthe inverter has got any damage or deformation during the transportation and handling.
® Checkifthere is one piece of HY series inverter and one copy of the instruction manual

available when unpacking it.

Check the information on the nameplate to see if the specifications meet your order ( Operating
voltage and K VA value).

Check if there is something wrong with the inner parts, wiring and circuit board.

Check if each terminal is tightly locked and if there is any foreign article inside the inverter.
Check if the operator buttons are all right.

Check if the optional components you ordered are contained.

2. Nameplate Description of HY Series Inverter

Model: HY A 07D5 43 B

Software Version

Voltage Rating, 43 means 3-phase 380V

Inverter Capacity, 07D5 means 7.5KW
Serial No.,
Trade Mark

02

\

03

Il . Safety Precautions

1. Before the Power-up

/4" — THE USE OF MANUAL

Check to be sure that the voltage of the main circuit AC power supply matches the input voltage of
the inverter.

The symbol, [E], represents ground terminals. Be sure to make correct ground connection of the
earth terminals of the motor and the inverter for safety.

No contactor should be installed between the power supply and the inverter to be used for starting
or stopping of the inverter. Otherwise it will affect the service life of the inverter.

R.S.T terminals are power input terminals, never mixed with U.V.W terminals. Be sure that the wiring
of the main circuit is correct. Otherwise it will cause damages of the inverter when the power is applied
To it.

Do not carry the front cover of the inverter directly when handling. It should be handled with the
base to prevent the fall-off of the front cover and avoid the dropping of the inverter, which may
possibly cause the injuries to people and the damages to the inverter.

Mount the inverter on a metal or other noncombustible material to avoid the risk of fire.

Install the inverter in a safe location, avoiding high temperature, direct sunlight, humid air or
water.

Keep the inverter from the reach of children or persons not concerned.

The inverter can only be used at the places accredited by our company. Any unauthorized
working environment may have the risks of fire, gas explosion, electric shock and other incidents.
Install a heat sink or other cooling device when installing more than one inverter in the same
enclosure so that the temperature inside the enclosure be kept below 40°C to avoid overheat or the
risk of fire.

Be sure to turn off the power supply before dissembling or assembling the operation keypanel and
fixing the front cover to avoid bad contact causing faults or non-display of the operator.

® Do not install the inverter in a space with explosive gas to avoid the risk of explosion.

® [fthe inverter is used at or above 1000m above seal level, the cooling efficiency will be worse, so
please run it by de-rating.

® Do not install any contactor and other components of capacitor or varistor on the output side of
the inverter. Otherwise it will cause malfunctions and damages of components of the inverter.Do
not install any switch component like air circuit breaker or contactor at the output of the inverter.
If any of such components must be installed because of the requirements of process and others, it
must be ensured that the inverter has no output when the switch acts. In addition, it is forbidden to

install any capacitor for improvement of power factor or any varistor against thunder at the output.

Otherwise it will cause malfunctions, tripping protection and damages of components of the
inverter. Please remove them as shown in the below diagram.

® ]t will affect the service life of the inverter if a contact is connected to the front end of input of the
inverter to control its starts and stops. Generally it is required to control it through FOR or REV
terminals. Special attention should be paid to its use in the case of frequent starts and stops.

® Please use an independent power supply for the inverter. Do avoid using the common power
supply with an electrical welder and other equipment with strong disturbance. Otherwise it will
cause the protection or even damage of the inverter.

U

Inverter v

® Do not plug the connectors of the inverter during the power up to avoid any surge into the main
control board due to plugging, which might cause the damage of the inverter.
® Always have the protective cover in place before the power up to avoid electrical shock injury.

2.During the Power-up

3. During the Operation

® Never connect or disconnect the motor set while the inverter is in running. Otherwise it will
cause over-current trip and even burn up the main circuit of the inverter.

® Never remove the front cover of the inverter while the inverter is powered up to avoid any injury
of electric shock.

® Do not come close to the machine when the fault restart function is used to avoid anything
unexpected. The motor may automatically restart after its stop.

® The function of STOP Switch is only valid after setting, which is different with the use of
emergent stop switch. Please pay attention to it when using it.

04

74"\ — THE USE OF MANUAL

e B

05

Do not touch the heat sink, braking resistor, or other heat elements to avoid being scald.

Be sure that the motor and machine is within the applicable speed ranges before starting
operation because the inverter is quite easy to run from lower speed to higher speed.

Do not check the signals on circuit boards while the inverter is running to avoid danger.

Be careful when changing the inverter settings. The inverter has been adjusted and set before ex-
work. Do not adjust it wantonly. Please make proper adjustments according to the required
functions.

® Do consider the vibration, noise and the speed limit of the motor bearings and the mechanical
devices when the inverter is running at or above the frequency of 50Hz.

Il . Standards and Specifications
1. Particular Specifications

Type Input Voltage m)'v")e" c'%‘é%ré?; 8&:%% sn‘(h:(ct,a%:e
HY00D423B | SndefifeePhase | g4 1.0 25 04
HYOD7523B | SndleiraePhase | 75 2.0 5.0 0.75
HY01D523B Single Ve 1ese |15 28 7.0 1.5
HY02D223B Single & Inee Phase | 92 4.0 10 22
HYOD75438 30 380V 50Hz | 0.75 2.2 27 | 075
HY01D543B 30 380V 50Hz 15 3.2 4.0 15
HY02D243B 30 380V 50Hz 22 4.0 5.0 2.2
HY03D743B 30380V G0Hz | 3.7 6.8 8.5 37
HY05D543B 30 380V 50Hz 5.5 10 125 | 55
HY07D543B 30 380V 50Hz 7.5 14 175 | 75
HY001143B 30 380V 50Hz 1 19 24 11
HY001543B 30 380V 50Hz 15 26 33 15
HY18D543B 30380V 50Hz | 185 32 40 185
HY22D243B 30 380V 50Hz 22 37 47 22
HY30D043B 30 380V 50Hz 30 52 65 30
HY37D043B 30 380V 50Hz 37 64 80 37
HY45D043B 30 380V 50Hz 45 72 91 45
HY55D043B 30 380V 50Hz 55 84 110 55
HY75D0438B 30 380V 50Hz 75 116 152 75

HY90D043B 30380V 50Hz 90 134 | 176 90
HY110D43B 30380V 50Hz | 110 160 | 210 110
HY132D43B 30380V 50Hz | 132 193 | 253 132
HY160D43B 30380V 50Hz | 160 230 | 304 160
HY200D43B 30380V 50Hz | 200 200 | 380 200
HY220D43B 30380V 50Hz | 220 325 | 426 220
HY250D43B 30380V 50Hz | 250 381 | 500 250
HY280D43B 30380V 50Hz | 280 427 | 560 280
HY315D43B 30380V 50Hz | 315 | 460 | 605 315
Mini Specifications

Type Input Voltage | {ONE" g%éfa’%; &:%:\tt STEE‘;:;P
HY-MOD4A S 30t 0.4 1.0 2.5 0.4
HY-MOD75A S a0k 075 | 20 | 50 | 075
HY—M1D5A S o 15 28 | 70 | 15
HY-MO0D4B Three, Ehase 0.4 1.0 15 0.4
HY—-MOD758 oY S0 075 | 22 27 | 075
HY-M1D58B oY 5o 15 32 | 40 15

2. General Specifications

Inverter Series | HY-[[]
Control Mode SPWM
Input Power 330~440Vfor 380V power; 170~250for 220V power: 50Hz/60Hz

5-Digits Display &
Status Indicator Lamp

Displaying frequency, current, revolution, voltage, counter,
temperature, forward or reserve running, and fault, etc.

Communication Control | RS-485
Operation Temperature | —10~40T
Humidity 0-95% Relative Humidity ( without dew )
Vibration Below 0.5G
- Range 0.10~400.00Hz
8| Accuracy | Digital: 0.01% (~10~40C ) , Analog: 0.1% (25%10C)
5 Setting Resolution | Digital: 0.01Hz, Analog: 1%. of Max. Operating Frequency
E Output Resolution| 0.01Hz
g Operator SettingMethod | Press directly —[A][V] to set
% Analog SettingMethod| External Voltage 0-5V, 0-10V, 4-20mA, 0-20mA.

06

74"™"— THE USE OF MANUAL

_ e —

Ramp Control Selectable 4-speed steps ramp-up and —down time (0.1-6500s).
V/F Curve Set V/F curve at wil
Torque Control | Torqueincrease is settable by max. 10.0%. The starting torque can reach 150% at 1.0Hz.
Q 6 multi-function input terminals for 8—speed steps control, program operation,
3 | Multi-Inputs switching of 4-speed Ramp, UP, DOWN function, counter, extenal emergency
2 stop and other functions.
S
3 - 5 multi-function output terminals for displaying of running, zero speed, counter,
g Multi-Outputs extermnal abnormity, program operation and other information and wamings.
AVR (auto voltage regulation), Deceleration stop or free—stop, DC brake, auto reset
Other Functions | and restart, frequency track, PLC control, traverse function, drawing control, auto
energy-savings, carrier adjustable by max. 20KHz, etc.
Overload Electronic relay protection motor Drive ( for constant torque 150%/1 min.
Protection For the kinds of fan 120%/1min. )
- FUSE Protection | FUSE broken, Motor stops.
.
% Over-voltage | DC Voltage > 400V for220V class  DC Voltage > 800V for 380V class
%‘ Low Voltage | DC Voltage <200V for220V class  DC Voltage <400V for 380V class
3
;:," L“'ﬁa;:sf;f_’tp Restarted by frequency track after instantaneous stop.
%. Stall Prevention | Anti—stall during Acc/Dec run
3
@ | Output End Shorts | Electronic circuit protecting
Other Functi Fin over—heat protection, restriction of reverse running, direct start after
ther Functions power on, fault reset, parameter lock PID, one—drive-more, etc.

|V. Storage and Installation
1. Storage

The inverter must be kept in its original package box before installation. Pay attention to the
followings when keeping it in storage if the inverter is not used for the time being;:

It must be stored in a dry place without rubbish or dust.

The suitable temperature for storage is between -20°C and +65°C.
The relative humidity required is 0-95% without condensation.
There is no corrosive gas or liquid in the storage ambience.

It's better to lay the inverter on a rack and keep it in a proper package.

07

® [tisbetter not to store the inverter for long time. Long time storage of the inverter will lead to the

2.

deterioration of electrolytic capacity. If it needs to be stored for a long time make sure to power it
up one time within a year and the power-up time should be at least above five hours. When
powered up the voltage must be increased slowly with a voltage regulator to the rated voltage
value.

Installation Site and Environment

The inverter should be installed at the following location:

Ambient temperature -5°C to 40°C with good ventilation.

No water drop and low moisture.

Free from direct sunshine, high temperature and heavy dust fall.
Free from corrosive gas or liquid.

Less dust, oil gas and metallic particles

Free from vibration and easy for service and inspection.

Free from the interference of electromagnetic noise.

Attention: The ambient conditions of the inverter will affect its service life.

. Installation and Direction

There must be enough space left around the inverter for easy maintenance and cooling. See
Diagram .

The inverter must be installed vertically with the smooth ventilation for effective cooling.

If there is any instability when installing the inverter, please put a flat board under the inverter
bottom base and install it again. If the inverter is installed on a loose surface, stress may cause
damage of parts in the main circuit so as to damage the inverter.

The inverter should be installed on non-combustible materials, such as iron plate.

If several inverters are installed, upper and lower, together in one cabinet, please add heat
dissipation plates and leave enough space between the inverters. See Diagram.

_ 120
N
—>
//7

o

« 50 __, [ 50

Fy

v
8sg
=

\

&

—

UNIT:mm =
—» —

120
!
B8
o

—_—

09

/4" — THE USE OF MANUAL

V. Wiring

1. Main Circuit Wiring Schematic Diagram

Power supply: Verify that the inverter's rated voltage coincides with the power supply
voltage to avoid a damage of the inverter.

No fuse breaker:Refer to the related list.
Ground fault circuit interrupter: Use one of anti-high harmonic.

Electromagnetic contactor:
Note: Do not use the electromagnetic contactor as the on/off button of power supply for
the inverter.

AC reactor:Itis recommended to install an AC reactor for power factor improvement if
the input capacity is more than 1000K'VA.

Inverter:

® Be sure to make correct connections of the main circuit wires and control signal
wires of the inverter.

® Be sure to make correct setting of parameters for the inverter.

2. Description of Terminal Block

1) Arrangement of Main circuit Terminals

HYOD4043B~HY02D243B  HY0D4023B~HY03D4023B

R S T P Pr U Vv W E

DD DD DD D DD

L |

HY04D043B~HY05D043B HY04D023B

E R S T P Pr U V W

DD DD DD D DD

HY11D043B~HY30D043B
R S T E U Vv W

DD D o | DPID D

Mini Specifications: HY-MJA  HY-MOB

The power source is put into through the R.S.T terminals and put out of the U.V.W terminals.The 220v
can connect willfully two phase of R.S.T.

(2) Arrangement of Control Circuit Terminals

|@F| DRVIDCM| sPL|sPM SPHRST] REV] FOR|ACM| V0 | 10v) 5
| Fa | FC | FB \+24v|DCM| — |45V P\CMI ALl Vi |RS+|RS-J T2 3

Notes:Please short circuit the 2-3 foot of J1 terminal when using the board potentiometer .
Like chart:
12 3
Please short circuit the 2-3 foot of J1terminal when using the external connection potentiometer
or the external power supply.
Like chart:
12 3

Mini inverter terminals

| MB I MA | MA | |DRV|COM| SPLISPMlSPHl RST| REV| FORl RS+| RS-I Al |GND| VO |+5V|

Note: Al is the exterior analogue voltage or current input end, joint the parameter menu of Pd070.

3) Function Description of Main circuit Terminals

Symbol Function Description
RST Iljput terminal of AC line power. ( 220V class, for both single/three phase,
single phase connected to any two phases )
u.v.w Output terminal of the inverter
P.Pr Connector for braking resistor.

P1P Connector for DC reactor (When using a DC reactor the jumper shall be
removed.

E Ground terminal: the third method of grounding for 220V and special
grounding for 380 V of Electrical Engineering Regulations.

10

.

THE USE OF MANUAL

o ———

4) Function Description of Control Circuit Terminals

Symbol Function Description Factory setting
FOR Multi-Input 1 Forward run
REV Multi-Input 2 Reverse run
RST Multi-Input 3 Reset
SPH Multi-Input 4 High speed
SPM Multi-Input 5 Middle Speed
SPL Multi-Input 6 Low Speed
DCM Common Terminal of Digital and
(COM) Control Signals
+10 Power Supply for Speed Setting +10V
Vi Analog Voltage Frequency Reference Input gpggaﬁl\{]g?:é%i%%”d'"g to the highest
Al Analog Current Frequency Reference Input g‘;g?a"tmgcgggﬁggggmg to the highest
ACM Common Terminal of Analog and
(GND) Control Signals
DRV Multi-Output 1 (Optical couple output)
DC24V/100mA
UPF Multi-Output 2 (Optical couple output)
FA(MB)
FB(MA) Multi—-Output 3 (N/O or N/C) 3A/250V
FC(MA)
VO Output terminals of digital frequency 0~10V
RS+ RS- RS485 Communication port

11

3. Basic Connection Diagram

The wiring of the inverter is divided into two parts, main circuit terminal connections and control
circuit terminal connections. The user can see the main circuit terminals, and the control circuit
terminals after removing the cover of enclosure. The terminals must be connected correctly as the
following wiring circuit diagrams.

Braking Resistor

R.S.T Input current . T
If the single—phase
source meets two
willfully J bR P N
N\ i uo N U.V.W Qutput current.
—O0 _O0—9 s VvV p———— Connect the three-phase
5 o T wo——" electric appliance
—E
24 vRitovisv +5V
10K Q I S VI
Potentiometer Control ACM(GND) +24V

FC(MA) Multi-Output
FA(MB) 3A/250VAC
FB(MA) 3A/30VDC

Input current

DRV  Multi-Output
UPF 24V/100mA

ndui-nniy

Output terminals of digital
frequency

L iQ sPL Vo
TP DOMCOM) rée«(] | 485 0~10V/10mA
Note: The above wiring diagram explained that only supplies the reference, take the actual product as the
standard. The diagram is subject to change without notice.

4. Precautions on Wiring

1)For the main circuit wiring:

® While wiring the sizes and specifications of wires should be selected and the wiring should be
executed according to the electrical engineering regulations to ensure the safety.

® [t is better to use shielded wire or wire and conduit for power cord and ground the shielded layer
or two ends of wire conduit.

® Be sure to install a Non Fuse Breaker (NFB) between the power supply and the input terminals

(R.S.T). (If using ground fault circuit interrupter, please choose one corresponding to high

frequency)

Never connect AC power to the output terminal (U.V.W) of the inverter.

Output wires mustn't be in touch of the metal part of the inverter enclosure, or it will result in

earth short-circuit.

® Phase-shifting capacitors, LC, RC noise filters, etc, can never be connected to the output
terminals of the inverter.

® The main circuit wire must be enough far away from other control equipments.
When the wiring between the inverter and the motor exceeds 15 meters for 220V class or 30
meters for 380V class, much higher dV/dT will be produced inside the coil of the motor, which
will cause the destruction to the interlay or insulation of the motor. Please use a dedicated AC
motor for the inverter or add a reactor at the inverter.

12

/4" — THE USE OF MANUAL
\

® Please lower the carrier frequency when there is a longer distance between the inverter and the
motor. Because the higher the carrier frequency is the bigger the leakage current of high-order
harmonics in the cables will be. The leakage current will have unfavorable effect on the inverter
and other equipment.

2) For control circuit wiring (signal line)

® The signal line should be separately laid in a different conduit with the main circuit wire to avoid
any possible interference. ‘

® Please use the shielded cable with the size of 0.52mm for signal lines.

® Use the control terminals on the control panel correctly according to your needs.

3) Grounding

® Grounding terminal E. Be sure to make correct grounding
220V class: The third grounding method (Grounding resistance should be 100Q or lower.)
380V class: The special third grounding method (Grounding resistance should be 10Q or lower.)

® Choose grounding wires according to the basic length and size of the technical requirements of the
electric equipment.

® Do avoid sharing grounding wire with other large power equipment such as electric welder, power
machine, etc. The grounding wire should be kept away from the power supply wires forlarge
equipment.

® The grounding method for several inverters together should be done as the first and second diagrams
below. Avoid the third loop.

® The grounding wire must be as shorter as possible.

e
S

(1) Good (2) Good (3) Not good

13

VI. Instruction of the Digital Operator
1. Description of the Digital Operator

LED Display Zone
indicating For., Rev.,
frequency, current,” | [ ]
revolution, etc.

POWER FOR  REV Hz A ROTT

Run key —

RUN STOP

Stop/Reset key

FOR/REV Switch —— PRGM

A

<II
Al

(DISP)Shiftkey —

Main Display Zone
indicating frequency,
current, ACV,DCV,
revolution, counter,
temperature, etc.

Speed controller

—— Function key

—— Set Key(Enter)

power
Value change key

UG TAL KEYPAD

LED Display Zone

indicating For., frequency,

current, revolution

FORJ Hz | A JROTT]

FOR/REV Switch

(DISP)Shift key

Value change key

Speed controller

-FIR A PROG—
-SHIFT W SET—

_
L2 Ia;!ﬁ-— Stop/Reset key

Main Display Zone 1
indicating frequency,
current, ACV, DCV,
revolution, counter,
temperature, etc.

Function key

Reset key

Run key

Main Display Zone 2

NOTE:The LED main display zone demonstrates by 5 nixietubes, the main display zone 2

demonstrates the 5th d1g1t

Example: 12345, 1234 digit in the main display zone 1, digit 5 in the main display zone 2.

14

.

THE USE OF MANUAL

o —

2.Description of Indicator Lamp Status

1) Description of Indicator Lamp Status

Indicator lamp Status Description
FOR on The motor is in forward rotation.
REV on The motorisin reverse rotation.
HZ on Displaying set frequency or output frequency.
A on Displaying output current.
ROTT on Displaying rated motor revolution
HZ A on Displaying DC voltage.
A ROTT on Displaying AC voltage.
HZ ROTT on Displaying counting value.
HZ AROTT on Displaying internal temperature of the inverter.

2 ) Description of Display Items

Display

CCrmn

O
3
3

=
Il

T
)

1M
=3

Indic.lamp {{ on Meaning

HZ A R/min Present output frequency is 50.00HZ
g o O

HZ A R/min Present set frequency is 50.00HZ
g O O

HZ A R/min Present set frequency is 50.00HZ 3.0A
O O d

HZ A R/min Present output revolution is 1440r/min
O O d

HZ A R/min Present DC voltage is 510.1V
o O d

HZ A R/min Present AC voltage is 380.0V
o o d

HZ A R/min Present inverter's temperature is 35.0C
IONN ORI O

C
o

“nCcitn
A0S

J
J
[
1

HZ A R/min

g o O

HZ A R/min

o O

HZ A R/min

o O

HZ A R/min

o O

HZ A
o O

R/min

O

O

O

0]

3. Description of Operation Examples

Present target value of PID is 50.0%

Present feedback value of PID is 48.0%

Present time of power-onis 12 hours

Total run time of inverteris 108 hours

Procedures Display Indicator Lamp Explanation
OP%V!:tiro%péf Dsp2.0 Flash FOR HZ Self detect when power-up, display version no.
? —Vr2.00
power —000.00 @] (Flashing) and finally set frequency.
PRGM Pd000 FOR HZ Enter programming Display the
i ¢ @] function of Pd000
I(E';E_EFF; ooo,oﬁ FOR }g Display the contents of Pd003
A~ 50.00 FOR HZ Change the content of PD003
ENYER END—50.00 ¢ @} Confirm changed value.
PdOO Display END 50.00 Pd004
| Q FOR HZ
PRGM 050.;§ 0 Back from programming
\ £50.00 FOR HZ Display running and operating
RUN I ) d @] frequency
i o | T 50.00 - FOR HZ Monitor screen switching, display
E,_lﬁcf r000~r 50.00 @] @] output current
! F: 50.00 FOR HZ Monitor screen switching, display
PRGM Q Q output current

Present counter's value is 105

16

17

/4™ — THE USE OF MANUAL

4 01440 FOR A Monitorscreen switching, display
DISP @) @) revolution
| r FOR ROTT /| Switchback to main screen, display
PROG r50.00 @) @] set frequency
| r FOR HZ Switch of For.Rev. rotation, display
JOG r 50.00 O g the status of Rev rotation
l ] FOR HZ 1 S iteh to adjustable
A O50./Q o o witch to adjustable frequency
| \ FOR HZ Adjust set frequency, i.e. the value
~A 00-00 o d of Pd003
| , ,
030.00 FOR HZ Confirm changed value, write to
ENTER o d Pd003 as value
\ C¥%0.00 FOR HZ Stop
STOP R0 Z o
Note:

@ ¢ means flashing. & means bright.
@ For monitoring AC, DC, T and other items they can be only switched and displayed after the

parameter setting.
@ When it is powered up again after a power breakdown the inverter will display the screen previous
to the power breakdown after its self detection.

VI. Commissioning

1. Important Checks before the Commissioning

If there is any wrong connected wires? Pay special attention to the terminal of U.V.W; Make sure
the power supply wires are connected to R.S.T, not U.V.W.
If there is any metal powder or wires left on the base plate of the inverter or the terminal block,
which may cause short circuit.
If screws are tightly locked and if the connecting parts are loose.
If there is any short circuit or earth fault at outputs.

2. Commissioning Methods

The procedure of the operator is factory set up for the control mode of HY series. The
commissioning can be carried out through the digital operator. Generally, the commissioning can be
conducted at 5.00 Hz.

o ——

¢ O

Procedures Display Indicator Lamp Explanation
Powerup | disp1.1—=Vr2.0 FOR HZ Self detect when power up, display
y D¢de @] version no. and finally set frequency
v/ FOR HZ Switch to adjustable frequency
A 000.60 O on the panel
) \/ FOR HZ Change set frequency, i.e.
< A 0R0.00 ¢ @] The value of Pd003
\ T 50.00 FOR HZ Confirm changed value
ENTER C ¢ O
| C FOR HZ
|
RUN - 50.00 o o Run at 50Hz
' Cl FOR HZ
STOP F papd Stop

Note: I means indicator lamps is on; ¢ means indicator lamps flash;

18

.

n\

THE USE OF MANUAL

VIl.Function List

Parameters Function List 1

. Ran Factor
gglt’s Code Function gs:ct?ogzgplanation Settin;
PDO000 Parameter Lock | O: Invalid 1: Valid 0
Source of Run 0: Operator 1: Externalterminal
PDOO1 Commands 2: Communication port 0
Source of 0: Operatorboard 1: Simulation
Frequency 2: Communication port
PD003 Main Frequency | 0.00~400.00 Hz *
PD004 Base Frequency | 0.01~400.00 Hz 50.00
PD005 | MaxOperating Frequency | 50.00~400.00 Hz 50.00
g PD006 | Intermediate Frequency [ 0.01~400.00 Hz 2.50/3.0
g. PDO07 Min. Frequency | 0.01~20.00 Hz 0.50
: PD008 Max. Voltage 0.1V——-* 220/380
o PDO009 Intermediate Voltage | 0.1V—-—-* *
3 PD010 | Min. Voltage 0.1~50.0V *
o PDO11 Frequency Lower Limit | 0.00~400.00 Hz 0
» PD012 | Reserved
PD013 Parameter Reset| 1: Restorethe factory setting. No other function. 00
PD014 Accel. Time 1 0.1~6500.0S *
PD015 Decel. Time 1 0.1~6500.0S *
PD0O16 Accel. Time 2 0.1~6500.0S *
PDO017 Decel. Time 2 0.1~6500.0S *
PDO018 Accel. Time 3 0.1~6500.0S *
PDO019 Decel. Time 3 0.1~6500.0S *
PDO020 Accel. Time 4 0.1~6500.0S *
PD021 Decel. Time 4 0.1~6500.08 *
PD022 Reserved
PD023 Rev. Rotation Select | 0: Rev Run forbidden; 1: Rev Run Enable 0
PDO024 STOP key select | 0: STOP Invalid 1: STOP Valid 1
oS -
g g PD026 | Stopping Mode (1) ggzziﬁ:gtggp“"p 0
® ©| PD027 | StartingFrequency | 0.1~10.0 Hz 0.5
3 PD028 Stopping Frequency [ 0.1~10.0 Hz 0.5

19

PDO029 Braking time at start 0~25.0 0.0
PD030 Braking time at stop 0~25.0 0.0
PD031 DC Braking level 0.0~20.0% 2.0
PD032 Frequency track time 0.1~20.0S 5.0
PD033 Current level for frequency track | 0.0~200.0S 150.0
Voltage rise time during
PD034 0.1~10S 0.5
frequency track
PDO035-
PD040 Reserved
PD041 Carrier frequency 0~15 *
PD042 Jogging Frequency 0.00~400.00Hz 5.00
PD043 S—-Curve Time 0~6500S 0
Parameters Function List 2
Cate . Set Range & Factory
gory Code Function Function Explanation| Setting
PD044 FOR (D1) 0: Invalid; 1:Run; 2: For rotation; 02
3: Rev rotation; 4: Stop; 5: FOR/
REV(D2 REV.; 6: Jog; 7: Jog For rotation; 03
PD045 (b2) 8: Jog Rev Rotation; 9:Timer1;
- 10:Timer2; 11:Reserved; 12:
o PD046 RST(D3) Overheat of heat sink or motor; 04
3 13:Emergent stop; 14:Reset;
5 PD047 SPH(D4) 15~16: Reserved ;17: Ramp 07
I~ select 1;18 :Ramp select2;19:
) PD048 SPL(D5) Multi-speed1 ; 20: Multi-speed 19
-] 2; 21: Multi-speed 3; 22: High
= speed; 23: Middle speed;24:
_g Low speed; 25: PID Start; 26:
Reserved; 27: UP function
[~ s
- PD049 SPM(DS) Counter 28: DOWN function; 20
o 29: Drawing;30: Reserved;31:
E- Counter; 32: Counter reset
2
= PD050 Y1 Output 0: Invalid; 1: Run; 2: Zero 01
Speed; 3: Fault indication; 4:
PDO051 Y2 Output Braking indication; 5: Set 03
Frequency reach; 6: In Accel.;
PD052 Terminals of FA,FB,FC |7:InDecel.; 8: Arbitrary 01
Frequency 1 reach;
9:Arbitrary Frequency 2 reach;

20

21

7y,

THE USE OF MANUAL

o ——

s|jeulwaa] 3ndinQ pue }nduj

10:Motor Overload alarm;

11:Overtorquealarm;

12:InverterOverloadalarm;

13:Counterreach;14~16:

Reserved;17:Low voltage

alarm; 18: Single stage end

’ indication; 20~26: Reserved,;

27: Drawing reach; 28:

PIDlower limit alarm; 29: PID

upper limitalarm; 30: Reserved;

31:Braking resistor act ;32:

Fan act.

Output of digital frequency
PD054 VO Output signals 0-7 0
PDO055 VO Analog output Gain | 0.0~100.0% 100
PD056 Skip Frequency 1 0.00~400.00 Hz 0.00
PD057 Skip Frequency 2 0.00~400.00 0.00
PD058 Skip Frequency 3 0.00~400.00 0.00
PDO059 Skip Frequency Range | 0.10~10.00 0.50
PD060 Uniform Frequency 1 0.00~400.00 Hz 0.00
PD061 Uniform Frequency 2 0.00~400.00 Hz 0.00
PD062 Uniform Frequency Range | 0.10~10.00 Hz 0.50
PD063 Timer 1 time 0~10.0 0.1
PD064 Timer 2 time 0~100 1
PDO065 Counting value set 00~65500 00
PD066 Intermediate Counter 0~65500 0
PDO067-
PD069 Reserved

Parameters Function List 3

Cate . Set Range & Factory
gory | Code Function Function Explanation| Setting
0:0~10V
1:0~5v
PD0O70 Analog Input 20~ 0
7 ginp 34-20mA
4:0~10V ,stacked 4~20mA
Exterior pulse of input
PDO071 Analog Filtering Constant | 0~50 20
PDO072 Lower Analog Frequency 0.00~400.00 Hz 50.00
PDO0O73 Higher Analog Frequency 0.00~400.00 Hz 0
s . 0: Positive direction
Bias Direction at Higher Frequenc :
Pdo74 9 quency 1: Negative direction 0
N 0: Positive direction
PDO75 Bias Direction at Lower Frequency . o 0
1: Negative direction
Analog Negative Bias 0: Not allowable.
PDO076 0
Reverse 1: Allowable.
. 0: Not memorized
PDO77 Up/Down Function 0
1: Memorized
0: 0.01HZ
PD078 Up/Down Speed 0
1: 0.1HZ
PDO079 Reserved
Cate . Set Range & Factory
gory | Code Function Function Explanation | Setting
= 0: Normal run;
=8 1: Internal control 16-speed;
~
1 . 2: External control 4 —speed;
% PD080 PLC Operation 3: External control 8-speed 0
3 4: Drawning
-y 5: Disturbance;
O
T
] 0: Stop after running for one cycle;
N Internal Control 1: Cycling run;
(=3 H 2: Auto stop after running for one cycle
6' PDO81 Multl—slpeeds (SuTOP(;Er inter\%ntilor?); ' Y 0
= Ope ration 3: Auto Run and Cycling

(STOP for intervention)

22

.

THE USE OF MANUAL

uonesadQ spaads-3}n

PDO82 | Rumna Breciaa e 0~255 (0: For 1: Rev) 0
PDO83 | RiCiferS speeds 0~255 (0: For 1: Rev) 0
PDO84 | parorespeedsPLC 0-65535 0
PDO85 | Rt C 0~65535 0
PDO86 Frequency 2 0.00-400.00 Hz 15.00
PDO87 Frequency 3 0.00-400.00 Hz 20.00
PDO88 Frequency 4 0.00-400.00 Hz 25.00
PD089 Frequency 5 0.00-400.00 Hz 30.00
PD090 Frequency 6 0.00-400.00 Hz 35.00
PDO091 Frequency 7 0.00-400.00 Hz 40.00
PD092 Frequency 8 0.00-400.00 Hz 0.50
PD093 Frequency 9 0.00-400.00 Hz 10.00
PD094 Frequency 10 0.00-400.00 Hz 15.00
PD095 Frequency 11 0.00-400.00 Hz 20.00
PD096 Frequency 12 0.00-400.00 Hz 25.00
b el Frequency 13 0.00-400.00 Hz 30.00
PDO98 Frequency 14 0.00-400.00 Hz 35.00
PD099 Frequency 15 0.00-400.00 Hz 40.00
PD100 Frequency 16 0.00-400.00 Hz 45.00
PD101 Timer 1 0.0-6500.0S 10.0
PD102 Timer 2 0.0-6500.0S 10.0
PD103 Timer 3 0.0-6500.08S 0.0
PD104 Timer 4 0.0-6500.08S 0.0
PD105 Timer 5 0.0-6500.08 0.0
PD106 Timer 6 0.0-6500.08S 0.0
PD107 Timer 7 0.0-6500.08 0.0
PD108 Timer 8 0.0-6500.0S 0.0
PD109 Timer 9* 0.0-6500.0S 0.0
PD110 Timer 10 0.0-6500.0S 0.0
PD111 Timer 11 0.0-6500.0S 0.0
PD112 Timer 12 0.0-6500.08 0.0
PD113 Timer 13 0.0-6500.08S 0.0
PD114 Timer 14 0.0-6500.0S 0.0
PD115 Timer 15 0.0-6500.0S 0.0
PD116 Timer 16 0.0-6500.0S 0.0

Parameters Function List 4

Cate . Set Range & Factory
gory | Code Function Function Explanation| Setting
PD117 AutoPLC Memory Function 0-1 0
PD118 Over-voltage Stall Prevention 0-1 1
PD119 Stall Prevention Level at Accel. 0-200 150
Stall Prevention Level at
PD120 Constant Speed 0-200 0
PD121 The Decel Time of Stall Prevention 0.1-25.5 5
Level at Constant Speed
. 0-200 150
PD122 Stall Prevention Level at Decel.
PD123 | Over-torque Detect Mode 0-3 0
PD124 Over-torque Detect Level 0-200 0
PD125 Over-torque Detect Time 0.1-20.0 1.0
PD126 Pulse Counter Memory 0-1 0
PD127-
Reserved
PD129
s PD130 Number of Auxiliary Pump 0~2 0
gn- PD131 Continuous Operating Time of Aux. Pumps 1~9000mim 60
=
g> PD132 Interlocking Time of Aux. Pumps 1~250s 5s
T
=2 PD133 High Speed Running Time 1~250s 60s
<
g PD134 | Low Speed Running Time 1~250s 60s
=
-
o PD135 Stopping Voltage Level 1~150% 95%
-]
z PD136 Lasting Time of Stopping Voltage Level 1~250s 30s
Y
=4 PD137 Wakeup Level 1~150% 80%
v
g PD138 Sleep Frequency 0.00~400.0 20.00
»
£ PD139 Lasting Time of Sleep Frequency 1~250s 20s
o©
PD140 Reserved
o=
Py = PD141 Rated Motor Voltage Set according to Motor nameplate *
% 9_:1 PD142 Rated Motor Current Set according to Motor nameplate *
E':S PD143 Motor pole number. 0210 04
@ 8- PD144 Rated Motor Revolution | 24000 1440
<)
3

24

25

THE USE OF MANUAL

PD145 Auto Torque Compensation
PD146 Motor no-load current
PD147 Motor slip compensation
PD148-
Reserved
PD149
PD150 Auto Voltage Regulation 0-1 1
PD151 Auto Energy Saving 0-20 0
PD152 Fault Restart Time 0.2-25 1
PD153 Restart after Instantaneous Stop | 0. Invalid 1: Frequency track 0
PD154 Allowable Power-Breakdown Time 0.1-5.0S 0.5
PD155 Number of Abnormal Restart 0-10 00
Parameters Function List5
Cate . Set Range & Factory
gory | Code Function Function Explanation| Setting
PD156 Proportional Constant (P) 0.0~1000.00% 100%
PD157 Integral Time (1) 0.1~3600.00S 5.0
S | PD1s8 | Differential Time (D) 0.01~10.00S 0
> Pd159 Target value 0.0~100.0% 0
o 0: set by the operator
3 T tval lect 1: setby external terminals
® Pd160 arget value selec (0-10V) 0
3 presert
PD161 PID upper limit 0~100% 100%
PD162 PID lower limit 0~100% 0%
no PD163 Communication Addresses 0-250 0
co
Eg PD164 Communication Baud Rate 0-3 0
g g PD165 Communication Data Method 0-5 0
=
= | Pdiee-
° Reserved
I~ Pd169

PD170 Display Items 0-5 7

PD171 Display Items Open 0-15 7
PD172 Fault Clear 00 10( 01 for Fault Clear ) *
PD173 Voltage Rating of Inverter | Set according to the model *

PD174 Rated Current of Inverter Set according to the model
PD175 Inverter Model
PD176 Inverter Frequency Standard 0: 50Hz 1: 60Hz 0

PD177 Fault Record 1
PD178 Fault Record 2 —
Note:

PD17 Fault R —
9 aultRecord 3 Means no fault record.

PD180 Fault Record 4 —

uoI3ouUNg 10}UOAl

PD181 Software Version

PD182 Manufacture Date Year: Month: Week: *
PD183 Serial No. *
Pd184-

Reserved
Pd250

X.Descriptions of Functions
PDO0O00 Parameter Lock
Set Range: 0-1 Unit: 1 Factory Setting: 0

0: Invalid.

1: Valid, i.e. the parameters are locked. Except this parameter other parameters can not be changed.
This parameter is set to prevent non-maintenance personnel from setting other parameters by mistake.
After the parameters are locked the operating frequency can be changed by pressing A or [J.

PDO001 Source of Operation Commands
Set Range: 0-2 Unit: 1 Factory Setting: 0

0: Setby the Operator
Operation commands are given via the digital operator.
1: Setby external terminals.
Operation commands are given via external terminals, i.e. multi-input terminals

26

/4"™\ — THE USE OF MANUAL
\

2: Setby communication ports.
Operation commands are given via communication ports.

PD002 Source of Operating Frequency
Set Range: 0-3 Unit: 1 Factory Setting: 0

0: Setby the operator. The operating frequency which given via the digital operator is Pd003.

1: Setby external terminals. Operating frequency is controlled by analog signals inputvia external
terminals. The signal type is determined by PD070. For the related parameters refer to PD070-PD076.
2: The MODBUS is given. Operating frequency is given via the serial communication.

PD003 Main Frequency **
Set Range: 0.00-400.00 Hz Unit: 0.01 Hz Factory Setting: 0.00

In the digital operator mode, the inverter will run at the set value of PD003. During running, the
operating frequency can be changed by pressing A or V. During multi- speed running, the main
frequency is taken as the frequency of Speed 1.

In the external control multi-speed mode, if PD002 is set to 1, i.e. given by an external terminal,
Speed 1 will be given by the analog of the external terminal.

The setting of main frequency is limited by the maximum operating frequency.

The related parameters of PD002, PD080 are adjustable during operation.

PD004 Base Frequency
Set Range: 0.01-400.00 Hz Unit: 0.1Hz Factory Setting: 50.00

This parameter must be set according to the rated frequency of operating voltage on the motor's
nameplate. Under normal conditions do not change the set value of base frequency at will. If it is
equipped with a special motor this value should be set properly according to the characteristics of
the motor's parameters. Otherwise it may cause the damage to the equipment.

PD005 Max. Operating Frequency
Set Range: 10.00-400.00 Hz Unit: 0.01 Hz Factory Setting: 50.00

This parameter is set for the maximum operating frequency of the inverter.
The following are several curves and set values often used for reference. Specific curves must be
set according to concrete characteristics of mechanical load.

27

00525 50 00525 s »
Curve of constant torque Curve of lower torque Curve of higher torque
PDO006 Intermediate Frequency

Set Range: 0.01-400.00 Hz Unit: 0.01 Hz Factory Setting: 2.50

Note: ** means this parameter is adjustable during operation.

This parameter is set for intermediate frequency of arbitrary V/F curve. If it is set improperly,
it will cause over-current or under-torque of the motor, or even tripping of the inverter.

This set value of intermediate frequency is limited by the set value of base frequency.

PD007 Min. Frequency
Set Range: 0.12-0.00 Hz Unit: 0.01 Hz Factory Setting: 0.50

This parameter is set for the min. starting frequency of V/F curve.
The following table has specific factory settings of V/F curve, accel./decal., time and carrier for
the inverter of AA. AB. AM series:

MOd(;:)de P4009 Pd001 P(ZO] Pd5O’I P04 1 MOd(::)de P%O] Pd001 P014 Pd501 Pd104
HY0OD423B | 15.0] 756 | 5 5 9 | 003043A 17 | 85] 30 | 30 4
HYOD75238 | 14.0 [ 7 8 8 9 | 003743A 16 | 8 35 | 35 4
HY01D5238 | 14.0 [ 7 10 | 10 [ 8 | 004543A 16 | 8 40 | 40 4
HY02D223B | 13.0| 65 | 10 | 10 | 8 [ 005543A 156 | 75| 456 | 45 3
HY03D7238 | 13.0 65 | 15 [ 15 | 7 [ 007543A 15 | 75| 50 [ 50 3
HYOD75438 | 22 | 11 8 8 9 | 022043A " 55| 260 | 250 | 2
HYOID543B | 22 | 11 10 | 10 | 8 | 025043A " 55| 260 | 250 | 2

28

29

/4™ — THE USE OF MANUAL

Code Pd01|Pd01|PdO1 Code|Pd01|Pd01 Pd01|Pd04
Pd009 Pd041 Pd014
Model 0] 4165 Mode 910 5 |1
HY0202438 21 |105( 15 | 15 8 | 028043A N 551 250 250 ( 2
HY03D7438 21 | 105 15 | 15 7 | 030043A 10 5 250 250 | 2
HY05D5438 20 | 10 15 ] 15 6 | 031543A 10 5 250 250 | 2
HY07D5438 20 | 10 | 20 | 20 6 | 034543A 10 5 250 ( 260 | 2
HY11D0438 | 19 | 95 | 20 | 20 | © [037543A | 10 | 5 | 250 250 | 2
HY15D0438 19 [ 95| 20 | 20 5 | 040043A 10 5 250 250 | 2
HY1gDs438 | 18 | 9 | 256 [ 25 | 5 |041543A | 10 | 5 | 250| 250 | 2
Hv200438 | 18 | 9 [ 25 | 25 | 5
Note: ®Ramp Time 2 = Ramp Time 1 x 2
@Ramp Time 3 = Ramp Time 2 x 2
@Ramp Time 4 = Ramp Time 3 x 2
@Min.Voltage Value = Intermediate Voltage Value/2
®The intermediate frequency is 2.5 for the system of 50Hz.
®The intermediate frequency is 3.0 for the system of 60Hz.
PD008 Max. Voltage
Set Range: 0.1-* Unit: 0.1V Factory Setting: 220/380V

This parameter should be set according to the rated value of the motor's namep late . The factory
setting is 380V for 380V class motor and 220V for 220V class motor. The setting range of this
parameter is restricted by the voltage rating of the inverter. In case of the motor relatively far away
from the inverter this set value can be increased properly.

PDO009 Intermediate voltage
SetRange: 0.15-10.0V Unit: 0.1V Factory Setting: *

This parameter is set for an intermediate voltage value of arbitrary VF curve. If it is set improperly,
it will cause over-current or under-torque of the motor, or even tripping of the inverter.

When the intermediate frequency is increased the voltage will increase the output torque and at the
same time also the output current. When changing this parameter please pay attention to monitoring
the output current to avoid the inverter's tripping due to over-current.

The factory setting of intermediate voltage for 220V class inverter is 15, while the factory setting
of intermediate voltage of 380V class inverter is 27.5.

This set value of intermediate voltage is limited by the set value of max voltage. When the voltage
is increasing to a certain value at intermediate frequency the torque compensation will lose its function.

When adjusting this parameter the output current of the inverter should be increased from low to
high slowly according to the load of machines until it meets the starting requirement. Do not be quick
to increase it by large amplitude. Otherwise it might cause the tripping of the inverter or the damage of
the machines.

PD010 Min. Voltage
Set Range: 0.1-50.0V Unit: 0.1V Factory Setting: *

This parameter is set for the min. starting voltage of V/F curve.
The factory setting of min. voltage for 220V class inverters is 8, and the factory setting of min.
voltage for 380V class inverters is 13.5.
This set value is limited by the voltage at the max. Frequency.

PDO011 Frequency Lower Limit
Set Range: 0.00-400.00 Unit: 0.01 Hz Factory Setting: 0.00

This is set for preventing workers from false operation to avoid over-heat or some other mechanical
faults, which might be caused due to too low operating frequency.
The setting of Frequency Lower Limit must be less than the set value of Frequency Upper Limit.

| PD012 Reserved |

| PD013 Parameter Reset |

When the value for a parameter is set improper or is abnormal for some reasons this parameter can
be setto 01 to restore it to the factory setting and then reset. After the parameters are locked (in case
of PD000=1) the parameters can't be reset. They can only be reset after unlock. For related parameters
refer to Pd000.

PDO14Accel. Time 1 **

Set Range: 0.16-500.0S Unit: 0.1S Factory Setting: *
PDO015 Decel. Time 1 **

Set Range: 0.16-500.0S Unit: 0.1S Factory Setting: *
PDO016 Accel. Time2 **

Set Range: 0.16-500.0S Unit: 0.1S Factory Setting: *
PD17 Decel. Time 2 **

SetRange: 0.16-500.0S Unit: 0.1S Factory Setting: *
PD18 Accel. Time 3 **

Set Range: 0.16-500.0S Unit: 0.1S Factory Setting: *
PD019 Decel. Time 3 **

Set Range: 0.16-500.0S Unit: 0.1S Factory Setting: *
PD020 Accel. Time 4 **

Set Range: 0.16-500.0S Unit: 0.1S Factory Setting: *
PD021 Decel. Time4 **

Set Range: 0.16-500.0S Unit: 0.1S Factory Setting: *

30

/4" — THE USE OF MANUAL
=

Ramp-up time means the time needed for the inverter to increase the frequency from 0Hz to the
maximum operating frequency (See t1 in the diagram). Ramp-down Time means the time needed for
the inverter to decrease the frequency from the maximum operating frequency to OHz (See t2 in the

diagram).
F
Max Oper. F :
:
1
[ > T
f— fe—s]
11 t2
Note:

The versions previous to Vr2.0 took SOHz as the base of ramp time.
HY-A Series inverter have altogether 4 Ramp Times. For Ramp Time 2.3.4 the user can select the different
ramp up or down time through the external terminals or switching of ramp time according to the actual needs.
In the internal control multi-speed operation, different ramp time can be selected through easy PLC.
Generally the default of the inverter is Ramp Time 1, which is factory set depending on the model.
Ramp Time 4 is for the jogging ramp time. For the factory setting of parameters refer to the table in Pd007.
The related parameters: PD044~PD049 and PD084,PD085

PD022 Factory Reserved

PD023 Rev Rotation Select
Set Range: 0-1 Unit: 1 Factory Setting: 0

0: Rev Rotation disable

1: Rev Rotation Enable

This function is suitable for the motor, which is not allowed to rotate reversely, to prevent workers from
false operation. When the reverse rotation is disabled, the motor can only rotate forward, not reverse.

PD024 STOP key
Set Range: 0-1 Unit: 1 Factory Setting: 1

0: STOP invalid.

1: STOP valid.

This parameter set is only valid when PD001 is setto 1 or 2.

When the control mode is set for external terminals or communication control, STOP key on the panel
can be chosen to be valid or invalid. When choosing it as valid, STOP key can stop the inverter in running.
When it needs to restart, the former running signal must be released before restarting the inverter.

PDO025 Starting Mode
Set Range: 0-1 Unit: 1 Factory Setting: 0

Two starting modes are available for the needs of different equipment.

31

0: Start from the starting frequency.

When PD029 is set to 0, i.e. DC braking is invalid at start, it starts running from the starting frequency.
When PD029 is set to any non-zero value, i.e. DC braking is valid at start, itl first performs a DC braking at
start, and then starts from the starting frequency.

For the Related parameters refer to PD027, PD029 and PD031.
1: Start by frequency track

This setting can be used for the restarting of large inertia load. When restarting, the inverter will trace the
former frequency from the set frequency downward. In case of large inertia equipment, when restarting, it
can implement the running command and track the former frequency right away without waiting for the
complete stop of the equipment to save time.

Note: When the inverter is restarted by frequency track, it will start tracking the frequency from its set
frequency downward, and search it at the highest speed. When restarting, the current becomes higher, and
over-current or stall may occur. So attention must be paid to the adjustment of current level of frequency
track. Generally, PD033 is adjusted around 100. The concrete value can be set according to the characteristics
of mechanical load.

Run comm. __]

SetF.
Ouput F
Output Power
PD026 Stopping Mode
Set Range: 0-1 Unit: 1 Factory Setting: 0

0: Decelerating Stop

When PD030 is set to 0, DC braking is invalid. When DC braking is invalid, the inverter will
decelerate to the stopping frequency, and then stop outputs, and the motor will coast to stop. When
PDO030 is set to any non-zero value, DC braking is valid, and the inverter will first decelerate to the
stopping frequency, and then stop by DC braking.

DC braking at stop is usually used for high position stop or for positioning control. It must be
noticed that frequent uses of DC braking will cause over-heat of the motor.

For the related parameters refer to PD028, PD030 and Pd031.
1: Coasting Stop

When the inverter receives a STOP command, it will immediately stop output and the motor will
coast to stop. When the coasting stop mode is selected, DC braking is invalid.

PDO027 Starting Frequency
SetRange: 0.1-10.0 Hz Unit: 0.1Hz Factory Setting: 0.5

32

/4" — THE USE OF MANUAL

Starting frequency is the initial frequency when the inverter is started. If the starting frequency is set
to 5.0Hz, the inverter will run between 5.0 Hz and the maximum operating frequency after its start at
5.0Hz.

For the related parameters refer to PD025, PD029 and PD031.

PD028 Stopping Frequency
Set Range: 0.1-10.0 Hz Unit: 0.1Hz Factory Setting: 0.5

When stopping the inverter will decrease its frequency to the stopping frequency and then stop
running or start DC braking to stop.

IfPDO030 is set to 0, DC braking is invalid at stop and the inverter will stop running.

If PDO030 is set for valid, the inverter will stop by DC braking when the inverter reduce to PD028.

For the related parameters refer to PD026, PD031 and Pd030.

PD029 DC Braking Time at Start
Set Range: 0.02-5.0S Unit: 0.1S Factory Setting: 0.0

Pd027

Pd029

This parameter is set for DC braking at start and the lasting time of DC braking current to the motor.
If it is set to zero it means DC braking is invalid.
DC braking at start is normally used in the application, in which the load is movable when the machine
is at stop, such as windmill. Because of the load existing before the inverter drives, the motor is often
in coasting with an uncertain rotation direction. So the DC braking can be executed before starting the
motor to prevent the inverter from tripping.

This setting is valid only when PD025 is set to 0. For the related parameters refer to PD025, PD029
and Pd031.

PD030 DC Braking Time at stop
Set Range: 0.0-25.0 Unit: 0.1S Factory Setting: 0.0

paozs | Y/ _

Pd030

33

Note: When this parameter is set to any non-zero value it starts DC brake at stop and sends the DC
braking time to the motor. DC braking at stop is often used for a high-level stop or positioning control.
When this parameter is set to zero it closes DC braking at stop.
This setting is valid when PD026 is set to 0. For the related parameters refer to PD026, PD028 and
Pdo31.

PD031 DC Braking Voltage Level

Set Range: 0.0-20.0% Unit: 0.1% Factory Setting: 2.0

This parameter is set for the DC braking voltage to the motorat start and stop.Itcan be adjusted for
different braking voltage. When adjusting the parameter it must be increased slowly from lower value
to high value until the sufficient braking torque is achieved.

The voltage at maximum frequency is 100% voltage.

PD032 Frequency Track Time
Unit: 0.1S

Set Range: 0.12-0.0S Factory Setting: 5.0

This parameter is set as frequency track time when the inverter is started by frequency track after
an external abnormality or temporary power breakdown. For starting or stopping of some large inertia
load, if restarting a machine after its complete stop, it will waste much time because of its large inertia
of load. But if the frequency track is started, it is not necessary to wait for the machine to come to a full
stop for restart. The inverter will trace the frequency from high to low with the set frequency. After
searching it will continue to accelerate to reach the set frequency.

PD033  Current Level for Frequency Track

Set Range: 0-200% Unit: 1% Factory Setting: 150

When the inverter is tracing the frequency this set value is taken as the level for output current.
When the output current is higher than this level the inverter will decrease the frequency to restore
the current below the level and then it will execute the frequency track again.

PDO034 Inverter Track Time of Up/down Factory Setting: 0.5

When the inverter is started by frequency track ,in the track process ,the voltege will up.when the
voltege up-speed increase ,the current will higher,the track process will faster. When the voltegr up-
speed decrease , the current will lower,the track process will slower.The generally setting way is the
low power machine establishes small, the high power machine establishes big.

PD035 Pd040 Reserved

PD041 Carrier Frequency
Set Range: 0-15

( Note: 015 corresponds to 020K Hz )
Unit: 1 Factory Setting: 5

The carrier frequency has some relation with the electromagnetic noise of the motor, and mean
while the level of the carrier frequency has certain relation with the heating capacity of the inverter
and the interference to the environment. See the following table:

Carrier Electromagnetic Heating Interference to
Frequency Noise Capacity the Environment
Low High Small Little
| | ! |
High Low Large Great

34

/4™ — THE USE OF MANUAL

Carrier Frequency Corresponding Table

Set Value 0[1]12(3|4]5]|6[7]|8]9(10{11(12|13{14]|15

Carrier

Frequency 011152 3[4[5]|7|8]9]10(11]13]|15(17]20

As shown in the table above, the higher the carrier is, the lower the electromagnetic noise of the
motor will be, but the stronger its interference to other systems will be and the greater the heating
capacity of the inverter will have. Under higher ambient temperature and heavier load of the motor
the carrier frequency should be decreased properly to improve the heat characteristics of the inverter.

The factory setting of carrier frequency is depending on the model.

*k

PDO042 Jogging Frequency
Set Range: 0.00-400.00 Unit: 0.01 Factory Setting: 5.00

The parameter set can realize the jogging function when the inverter is tested. The jogging operation
can be only achieved through the external terminals, which can be set by multi-input terminals. Jogging
frequency is limited by the frequency upper/lower limits. While the jogging function is implemented,
other running commands are invalid. The ramp-up time of jogging frequency is set by Ramp-up Time 4.
When the jog button is released the inverter will stop output immediately. In case of jogging function
please set the corresponding multi-input terminals to 07 or 08.

This function is only valid at stop. It is invalid at running. For the related parameters refer to PD044-
PD049.

PD043 S-Curve Time
Set Range: 0-6500S Unit: 1 Factory Setting: 1

This parameter can be set for no impact slow start or slow stop of the inverter when starting or
stopping. When starting S-curve the inverter will make accelerating or decelerating curve of different
speed rates according to Ramp Time.

AF

When PD043 is set as
0, S—curveisinvalid, @ | - - - -- - PDO043
i.e. it will accelerate
or decelerate in linear.
Without consideration [~ PDO14
of stall the actual
accel/decal time =
(PD014+PD043)/2.
The parameteris only
valid when Pd014 is
less than Pd043. PD043

BT

35

PD044 FOR (D1) Function Factory Setting: 02
Pd045 REV (D2) Function Factory Setting: 03
Pd046 RST (D3) Function Factory Setting: 04
Pd047 SPH (D4) Function Factory Setting: (7
Pd048 SPM (D5) Function Factory Setting: 19
Pd049 SPL (C6) Function Factory Setting: 20
Set Range: 00-32 Unit: No
01: RUN Running. It can be combined with other terminals to compose multiple control modes.
02: FOR Forward Rotation
03: REV Reverse Rotation
04: STOP Stopping
05: FOR/REV  Switching of FOR/REV rotation
06: JOG Jogging
07: Jog FOR
08: JogREV
09: External Control Timer 1 Start: When the contact is closed, the timer will start and begin to
count time. When the timer reaches the set point the corresponding multi-inputs will act.
10: External Control Timer 2 Start.
12: Over-heat of heat sink or motor: This contact can be used to detect over-heat of the heat sink or
motor to protect the motor and inverter.
13: Emergent Stop: Emergent stop. It can receive external emergent stop command or other fault
signals.
14: Reset: This terminal can be used for reset after a fault is removed.
15~16: Reserved.
17: Ramp Time 1: This terminal can be used to select the ramp time of the inverter.
18: Ramp Time 2: 4 kinds of ramp time are available for choice.
19: Multi-speed 1: 8-speed setting can be composed through Multi-speed 1, 2, 3.
20: Multi-speed 2
21: Multi-speed 3
22: Highspeed: High, middle and low speed can compose three kinds of operation mode
23: Middle speed with different frequencies. In the three terminals the high-end signal has
24: Low speed priority. Low, Middle and High Speed are determined respectively by Frequency 2,3,4.
25: PID Valid: When this contact is closed, PID function starts. PID Function start is only valid
during operation.
26: PLC Reset Suspend: This contact can be used to achieve the function of AutoPLC clear suspend.
27: UP Function: When the switch of this terminal acts the frequency setting of the inverter will be

increased or decreased by one unit. When the switch of the terminal is hold the frequency will
increase or decrease rapidly to a point and then increase or decrease.

36

\

37

28:

29:
31:

32:

/4" — THE USE OF MANUAL

Down Function at even speed. When the power is up again after the power breakdown the changed
frequency will not be memorized.

Drawing Start When this contact is triggered the drawing action starts.

Pulse Counter When this terminal is set for the counter it can receive the pulse signal of <250HZ
and counts.

Counter Reset When this contact acts it will clear the present counting values displayed, restore
C00 and restart counting.

Explanation:

1. Three multi-function terminals can be used for the connection
method of three-wire system for the realization of switching of
FOR/REV rotation, which is extensively applied in the cases of
FOR/REV switching of photoelectric switches.

(@ Select the multi-function terminals of D1, D2 and D3

@ Parameter setting:
PDO001=1 for external control PD044=02 for FOR rotation
PD045=03 for REV Rotation PD046=04 for Stop

® Action Description:
When triggering D1, the inverter will rotate forward (start);
When triggering D2, the inverter will rotate reverse;
When pressing STOP, the inverter will stop.

2. RUN, DCM, F/R can be used for Start, Stop and switching

K1 of FOR/REV:
b1 @ Select the terminals of D1 and D2
@ Parameter setting:
K2 PDO001=1 for external control

b2 PD044=01 for RUN function

PD045=05 for switching of F/R
DCM When K2 is opened it rotates forward, while K2 is closed it rotates
reverse.

3. Description of Ramp Time 1 and 2:

(@ This function is only valid when PD080 is set to 0, 2 and 3. Under
the disturbance and internal control multi-speed it is invalid.

@ Any two multi-inputs can be combined for 4 kinds of ramp time
for selection.

@ The related multi-inputs are set for Ramp Time 1,2. Take the
terminals of D4 and D5 as example, when the terminal of D4 PD 047
is set to 22 and the terminals of D5 PD048 is set to 23, D4 and D5
are now Ramp Time 1, 2.

D4 D5 Result

OFF OFF Ramp Time 1
ON OFF Ramp Time 2
OFF ON Ramp Time 3
ON ON Ramp Time 4

4. Function description of High, Middle and low speed terminals:

F A

H. speed
M.speed
L.speed

Main frequency

Run command

L. speed

L. Speed
RUN D6 D5 D4 Result
Main speed, the frequency runs
ON OFF OFF OFF at the set value of Pd003.
Low speed, the frequency runs
S ON OFF OFF at the set value of Pd086.
Middle speed, the frequency runs
ON ON/OFF ON o at the set value of Pd087.
ON ON/OEE ON/OEE ON High speed, the frequency runs
at the set value of Pd088.

Note:
(1) This function is only valid when PD08O is set to 2, i.e. for 4-Speed of external control.
(2 ) Ramp time is determined by Ramp Select terminal.
(3) When all high, middle and low speeds have signal inputs it will give priority in the sequence of
high, middle and low speed.

74"™— THE USE OF MANUAL

_ ¥ B

5. Description of UP and DOWN Function:

Max.operating Frequency A F
Set frequency

F.Lower Limit

Up Command
Down Command

uUpP DOWN Result

ON OFF Frequency increase

OFF ON Frequency decrease

ON ON Notincrease or decrease

Note:

(1) The function of UP and DOWN is only valid when the operator is selected for the source of the

operating frequency,i.e. PD002=0.

(2) When the UP terminal is closed the frequency of the inverter will increase.

(3) When the DOWN terminal is closed the frequency of the inverter will decrease.

(4) When both UPand DOWN terminals are closed at the same time the frequency will neither increase

nor decrease. Itisregarded as invalid.

(5) When the frequency reaches the max operating frequency it will stop increasing.

(6) When the frequency reaches the min frequency or its lower limit, it will stop decreasing.

(7) After a power breakdown the set value of PD003 will be memorized instead of the frequency.

(8) When using the function of UP and DOWN, the keys of A [Jof the panel are valid. After changing
the values it needs to press SET (ENTER) key for confirmation and then the inverter can implement
the action. Meanwhile the value will write to PD003, which will be memorized after a power
breakdown.

(9) When keeping pressing UP or DOWN, the frequency will increase or decrease rapidly to a point
and then increase or decrease at even speed.

(10) The value changed by UP or DOWN can be set through PD077 for confirmation of whether it
should be memorized or not memorized. For details refer to Pd077.

39

6.Function Description of Counter:

A CO0 C00

(O [ een [0 [T 00 0]

|
L

I
Counting Value reach ,—l—:—
I

Counting Value reset

Note:
(1) The signal width triggered should not be lower than 2 msec (t1. t2=2msec) .
(2) When the counting value is reached the corresponding multi-output contact will act.
(3) This counter can only count again after reset.
(4) When reaching to 65535 the counter will not count again.

PDO050 Y1-input Function Factory Setting: 01

PDO051 Y2-input Function Factory Setting: 03

PD052 FA. FB. FCInput Function Factory Setting: 01

PD053 Ka. KB Input Function Factory Setting: 03
Set Range: 00-32 Unit: 1

01:
02:

03:
04:
05:

06:
07:
08:

09:

In Run: The contact will act when the inverter has output or receives the running command.

Zero Speed: The contact will act when the output frequency of the inverter is less than its starting
frequency.

Fault Indication: The contact will act when the inverter detects abnormal conditions.

DC Braking Indication: The contact will act when the inverter is in DC braking.

Set Frequency Reach: The contact will act when the output frequency of the inverter reaches the

set frequency.

In Accel: The contact will act when the inverter is in ramp-up.

In Decel: The contact will act when the inverter is in ramp-down.

Uniform Frequency 1 Reach: The contact will act when the output frequency of the inverter reaches
the designated frequency (PD060).

Uniform Frequency 2 Reach: The contact will act when the output frequency of the inverter reaches
the designated frequency (PD061).

: Motor Overload Alarm: The contact will act when the inverter detects over-load of the motor.

40

/4" — THE USE OF MANUAL

11: Over-torque Detect: The contact will act when the inverter detects over-torque.
12: Inverter Over-load Alarm: The contact will act when the inverter detects over-load.
13: Set Counter Reach: The contact will act when the inverter implements the external counter and the
counting value is equal to the set value (PD065).
14: Middle Counter Reach: The contact will act when the inverter implements the external counter and
the counting value is greater than or equal to the set value (PD066).
15: External Control Timer 1 reach: The contact will act when the timer 1 reaches the set value..
16: External Control Timer 2 reach: The contact will act when the timer 2 reaches the set value
17: Low Voltage Alarm: The contact will act when the inverter detects low voltage.
18: Single Step End: The contact will act and generate one pulse when the inverter finishes a single
step in implementation of program operation.
19: Process End: The contact will act and generate one pulse when the inverter finishes all the steps(i.e.
after one cycle) in implementation of program operation
20: 4-°20mA disconnected: When Al input signal is disconnected and PD072 more than 2, the contact
will act.
: Auxiliary Pump 1: This contact controls the starting and stopping of auxiliary pumps . For details
refer to Operation of Multi-pumps.
26: Auxiliary Pump 2
27: Drawing reach: The contact will act when the drawing action is finished. The contact will auto
matically reset when the inverter stops.
28: PID Lower Limit Alarm: This contact will act when the PID feedback is smaller than the lower limit
(the set value of PD162).
29: PID Upper Limit Alarm: This contact will act when the PID feedback is greater than the upper limit
(the set value of PD161).
30: Braking Resistor Act: When the inverter is in running and the DC voltage reaches the braking voltage
the contact will act.
Electromagnetic Relay Act: When the contact pulls in, the corresponding multi-function terminal
will act.
32: Fanact: When the temperature of the inverter is increased or it is in running, this contact will act.

2

W

N

31:

—

PD054 Vo Input
Set Range: 0-7 Unit: 1 Factory Setting: 0

Functions: Output terminal of digital frequency, generating pulse or 010V analog. In combination with Pd055
it can be connected with a corresponding instrument with the measuring range below 10 to be used for external
monitoring.

0: 0~10V analog output, corresponding to output frequency. 0~ 10V corresponds to 0~Maximum operating
frequency

1: 0~10V analog output, corresponding to output current. 0~10V corresponds to 0~two times of the rated
current of the inverter.

2: Analog output, corresponding to DC bus voltage. 0~ 10V corresponds to 0~1000V.

3: Analog output, corresponding to AC output voltage. 0~10V corresponds to 0~510V/255V.

(Note: The machine type of three phase, 380V corresponds to 510V and the machine type of single phase, 220V
corresponds to 255V)

41

PD055 Vo Analog Output Gain
Set Range: 0.0-100.0% Unit: 0.1% Factory Setting: 100.0

This parameter can be used to adjust the output voltage value of Multi-output 6 to adapt to frequency
meters with different measuring range and also used to correcta frequency meter. For example, foran
externally connected frequency meter with the measuring range of 0~5V, a multi-function terminal
can be used to display its operating frequency. Then it can be corrected with this parameter. It can be
achieved by setting PD055=50 .

PD056 Skip Frequency 1 **
PDO057 Skip Frequency 2
PDO058 Skip Frequency 3

Set Range: 0.00-400.00 Hz Unit: 0.01Hz Factory Setting: 0.0
PD059 Skip Frequency Range >
Set Range: 0.10-10.00 Hz Unit: 0.01Hz Factory Setting: 0.5
F1
PDO058
PDO057
PD056

These three frequency skipping points are set for avoiding a mechanical resonance point. In case of PD05
9=0, all skip frequencies are invalid. The actual skip frequency range is two times that of PD059, as shown
inthe above diagram.

PD060 Uniform Frequency 1
PD061 Uniform Frequency 2

Set Range: 0.00-400.00 Hz Unit: 0.01 Hz Factory Setting: 0.00
Pd062 Uniform Frequency Range **
Set Range: 0.10-10.00 Hz Unit: 0.01 Hz Factory Setting: 0.50

Uniform
Frequency
Cdo61

Multi-Output T

Uniform Fequency

42

/4" — THE USE OF MANUAL

When the output frequency is more than the uniform frequency the corresponding multi-outputs will act.
The uniform frequency range acts as a hysteresis loop.

When the inverter is in the operation of multi-pumps, PD060 is used as high speed
frequency and PDO061 is set as low speed operating frequency. The definitions of the corresponding multi-
function contacts are changed.

PD063 Timer 1 Time

Set Range: 0.1~10.00 Unit: 1 Factory Setting: 0.1
PD064 Timer2 Time
Set Range: 1~100 Unit: 1 Factory Setting: 1

Timer 1 is a timer of 0.1s ~ 10.0s and Timer 2 is a timer of 1s ~ 100s. When the timer start at multi-inputs
is closed (on) the timer starts to count time. When it reaches the set time the corresponding multi-output contact
will act. When the timer start is opened (off) the timer time at the multi-output will be reset.

(At Input) Timer start E i > T
—
ON
A ON
(At Output) Timer T I > T

Pd063

For example, set PD063=5.0s. When the external control terminal (Multi-Input) is valid the output terminal
will be valid after five (5.0) seconds, the signal of which can be used to control other corresponding signals.

**

PD065 Counting Value
Set Range: 0-65500 Unit: 1 Factory Setting: 0

An external terminal of multi-function can be used as a trigger for the counter. When the counter reaches the
set value of PD065 the corresponding multi-output contact will act. After the counter is cleared and reset it will
start counting again. A proximity switch or optoelectronic switch can be used for the triggering signals.

PD066 Intermediate Counter
Set Range: 0-65500 Unit: 1 Factory Setting: 0

43

Refer to PD065.

PD067 PD069 Reserved

PDO070 Analog Input
Set Range: 0-4 Unit: 1 Factory Setting: 0

0: 0~10V 1: 0~5V 2: 0~20mA
3: 4~20mA 4: 0-10V 4-20mA stacked
This parameter can be set for different analog input signals.
When PD070=4, the output frequency =1/2 (U/Umax + I/Imax) X 50Hz
Among which: U: Analog Voltage =~ Umax: Maximum Analog Voltage
I: Analog Current  Imax: Maximum Analog Current

PD071 Analog Filtering Constant
Set Range: 0-50 Unit: 1 Factory Setting: 20

The setting of this parameter is related to the analog responding speed. The higher the value of PD071 is
set, the lower the analog responding speed will be.

PD072 Higher Analog Frequency

Set Range: 0.00-400.00 Hz Unit: 0.01Hz Factory Setting: 50.00
PDO073 Lower Analog Frequency

Set Range: 0.00-400.00 Hz Unit: 0.01 Hz Factory Setting: 0.00
PD074 Bias Direction at Higher Frequency

Set Range: 0-1 Unit: 1 Factory Setting: 0
PDO075 Bias Direction at Lower Frequency

Set Range: 0-1 Unit: 1 Factory Setting: 0

0: Positive direction

1: Negative direction

Bias direction means the instruction of FOR/REV rotation command. Positive bias indicates forward rotation
while negative bias indicates reverse rotation. For details refer to the diagram in Pd076.

PD076 Analog Negative Bias Reverse
Set Range: 0-1 Unit: 1 Factory Setting: 0

0: Negative bias Rev is not allowable.

1: Negative bias Rev is allowable.

The parameter group is set for the measuring range and zero point of the external analog terminals and can be
combined for any kind of curve to control the operation of the motor.

AF Setting: PD073=50 PD075=1 PD072=50
PD074=0 PD076=1
Rev. Area | 50 Hz For. Area Note: this curve can be easily used incomplicated applications
in combination with other curves. When using it the
instruction of FOR/REV run from external terminals is
still valid. When switching, the curve will turn reverse.

44

45

74"™— THE USE OF MANUAL

PD074=0 PD076=1
Note: this curve is a kind of special application of reverse ramp
setting. When using transmitter for the control of pressure,
temperature and others and while the control has higher
pressure and output signals but requiring the corresponding
commands of stop or deceleration on the inverter this curve

W Setting: PD073=50 PD075=1 PD072=50

—> can satisfy the demand properly.
ov 5V 10V B Properly
A F
40
Setting: PD073=50 PD075=1 PD072=50
PD074=0 PD076=1
> Note: this method is used extensively. The user can use it flexibly.
0 10V
4mA  20mA
M F
Setting: PD073=10 PD075=1 PD072=40
PD074=0 PD076=0
Note: the signal of 0Hz-40Hz (4~4.8mA) is invalid. It canbe
used to avoid noice disturbance. In harsh environment it is
. — better not to use signals below 1V for setting the operating
yd frequency of the inverter.
0 10V
4mA  4.8mA  20mA
2V-10V(4.8mA~20mA)

PD077 UP/DOWN Function
Set Range: 0-1 Unit: 1 Factory Setting: 0

0: Notmemorizedl: Memorized

This parameter can be sct for the selection of whether the values changed by the UP or DOWN shall be
memorized or not after stop. The changed values whether to be memorized or not means when they are
changed by UP or DOWN during operation and the inverter is restarted after stop these changed values
shall be memorized or not after restart. When PD077 is set to 0, the changed value will not be memorized
and when it is set to 1, the changed values will be memorized. The set values of PD003 will be memorized
after restart.

For the related parameters refer to PD044-PD049.

PD078 UP/DOWN Speed
Set Range: 0-1 Unit: 1 Factory Setting: 0

0: 0.01Hz. Minimum UP/DOWN speed is 0.01Hz.

1: 0.1Hz. Minimum UP/DOWN speed is 0.1Hz.

Through the changes of this set value the UP/DOWN speed unit can be adjusted to meet the needs of
different customers.

PDO079 Reserved —I

PD080 PLC Operation
Set Range: 0-5 Unit: 1 Factory Setting: 0

0: Normal operation, i.e. the inverter is running in the normal control mode.

1: Internal control Multi-speeds(16-speeds)

Note:

(D Main speed and 7-speeds composes 8-speeds.

@ The ramp time of each speed step is set by PD084,PD085.

® Running Time is set by Timer PD101~PD116. For the control steps not to be used the timer can be set to 0.

@ Running direction of each speed step is determined by PD082,PD083.

®In the internal control multi-speed operation the running time and direction are determined by the setting
of internal parameters. Any switching of external time and FOR/REV rotation is invalid.

2:External control 4-Speeds (Refer to the function description and diagram of three terminals of high,
middle and low speed in PD044~PD049)

3: External control Mulit-speeds

Multi-function Terminals Results

Specd1 | Spesd2 | Spesds
OFF OFF OFF Main frequency and frequencies are determined by PD003 or potentiometer.
ON OFF OFF Multi-speed 1 and frequency are determined by PD086.
OFF ON OFF Multi-speed 2 and frequency are determined by PD087.
ON ON OFF Multi-speed 3 and frequency are determined by Pd088.
OFF OFF ON Multi-speed 4 and frequency are determined by PD089.
ON OFF ON Multi-speed 5 and frequency are determined by PD090.
OFF ON ON Multi-speed 6 and frequency are determined by PD091.
ON ON ON Multi-speed 7 and frequency are determined by Pd092.

Note:

@ It is only valid to realize the external control 8-Speeds operation when Multi-inputs are set for Multi-
speed 1, 2, 3 and PD080 is set to 3.

@ Multi-speed 1, 2, 3 can be used to make up 7-Speeds and 8-Speeds adding the main frequency .

®) The frequencies of Speed Step 1 ~ Step 7 are determined by PD086~PD092.

@ Each ramp time is determined by the external multi-function terminal D1-D6.

® The directions of each program operation are determined by the external multi-function terminalsD1
-D6.

® The main frequency can be set in two ways. One method is to set it through PD003 and another is to
set it through the potentiometer. When PD002 is set to 1 the frequency of Main Frequency is set by
the potentiometer. For the related parameters refer to PD003, PD002 and PD086~PD092.

46

/4" — THE USE OF MANUAL

4: Drawing
This is a special parameter for the constant speed of unwinding and rewinding. By using this function
the linear speed constant in certain accuracy can be realized.

- A

PD086 |-----——-
PDO87 f-----Ff-—-----—----"S .
Pdoo3 |- { :
! :
T L Y > T
! 1
ﬂ ? :
Multi-input l_]_
Multi-output

Note:

O Through triggering of the external multi-function terminal the drawing action begins.

@ In implementation of the drawing action the actual running time is T=PD101 X 10.

® when the drawing action is finished the inverter will run at the constant seed of PD087 and the corre-
sponding multi-output contact will act at the same time. Until receiving the STOP command the
inverter will stop running and the multi-output contact will reset.

5:Disturbance (Traverse function)
This is a special parameter in the chemical fiber and printing and dying industries to realize the traverse
function. Except the commands of stop, external faults and emergency stop all other commands are
not accepted at running.

Note:

( The frequency at each inflection point is determined by PD003 and PD086.

@ Skip Frequency is determined by PD092.

® Running Time is determined by Timer PD101 and PD102.

@ The related parameters: PD003, PD086~PD116.

PDO081 Auto PLC
Set Range: 0-3 Unit: 1 Factory Setting: 0

: Stop after the program runs one cycle.

: Cycling running.

: Stop after it runs one cycle automatically (STOP for intervention) .

: Auto running and cycling (STOP for intervention)
This parameter setting is only valid when PDO08O0 is set to 4. For relevant parameters refer to PD003,
Pd080 and CD082~PD116.

W N - O

47

Explanation:

1.Stop after the program runs one cycle.
When the command of auto program operation is given, the inverter will run with each setvalue of
internal parameters. It will run for one cycle and then stop automatically. The inverter will not restart
and run until it receives another command of operation.

2.Cycling run.
When the command of operation is given, the inverter will run in sequence with the frequency of
every speed step and running time set by each of the internal parameters and will recycle. During
the cycling run, except the commands of stop, external faults and emergency stop, all other com
mands will not be accepted.

3.Stop after it runs one cycle automatically (STOP for intervention)

F Pd087
Pd0s8 Pd091

P4003 Pd092

Pd089

Pd101 \P‘“Of Pd103  Pd104 Pd105N9 1% pd107  pgos T
55055 Pd090

Note:

(D When the command of auto program operation is given the inverter will run with each parameters.
But it will stop first and then restart at changing of each step and will stop automatically after running
for one cycle. The inverter will not restart and run until it receives another command of operation.

(2 The frequencies of each speed step are set by PD003 and PD086 ~ PD092.

@ The running times of each speed step are set by PD101 ~PD108.

@ The running direction is set by P082

PDO082 PLC Running Direction of the Front 8-Speeds
PD083 PLC Running Direction of the Follow 8-Speeds
Set Range: 0-255 Unit: 1 Factory Setting: 0

This parameter is only valid when PD080 is set to 1 This parameter setting determine the
running direction of each frequency of PD086~PD092 and PD003 in the program operation.
The setting method is as follows:

The rotation direction is set first in the binary 8 bits mode, and then converted to a decimal
value for the setting of this parameter. For instance:

The parameter value 01001010 is converted to a decimal value:
1x2°%1x2%1x2'=64+8+2=74
Then PD082=74

PD083 means that set running direction of the follow 8-speeds(the algorithm likes Pd082)

PD084 Ramp Time of the Front 8—-Speeds

48

/4" — THE USE OF MANUAL

. £ B —

PD085 Ramp Time of the Follow 8—Speeds
Set Range: 0-65535 Unit: 1S Factory Setting: 0

This parameter is only valid when PD080 is set to 1.
This parameter is set to determine the ramp time values for the internal control multi-speed and each
speed. The setting method is as follows:

(D Determine each Ramp Time in the binary 2 bit mode

Bit1 Bit0 Ramp Time
0 0 Ramp Time 1 PD014, PD0O15
0 1 Ramp Time 2 PD016, PD017
1 0 Ramp Time 3 PD018, PD019
1 1 Ramp Time 4 PD020, Pd021

(@ Determine the Ramp time of each speed step in the binary 16 bit mode
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

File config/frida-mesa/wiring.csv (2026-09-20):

net | from_device | from_terminal | to_device | to_terminal | voltage_domain | logic | wire_color | wire_size | shield | fuse | status | notes
X_STEP | MESA7I95T | TB3-2 STEP0- | DRIVE_X | PUL- | 5V | common-anode active pulse |  |  |  |  | legacy-derived | Leave TB3-3 STEP0+ open
X_DIR | MESA7I95T | TB3-4 DIR0- | DRIVE_X | DIR- | 5V | common-anode |  |  |  |  | legacy-derived | Leave TB3-5 DIR0+ open
X_STEP_DIR_COMMON | MESA7I95T | TB3-6 +5VP | DRIVE_X | PUL+ and DIR+ | 5V | common-anode |  |  |  | PTC on Mesa | legacy-derived | Verify drive terminals and branch at drive
Y_STEP | MESA7I95T | TB3-8 STEP1- | DRIVE_Y | PUL- | 5V | common-anode active pulse |  |  |  |  | legacy-derived | Leave TB3-9 STEP1+ open
Y_DIR | MESA7I95T | TB3-10 DIR1- | DRIVE_Y | DIR- | 5V | common-anode |  |  |  |  | legacy-derived | Leave TB3-11 DIR1+ open
Y_STEP_DIR_COMMON | MESA7I95T | TB3-12 +5VP | DRIVE_Y | PUL+ and DIR+ | 5V | common-anode |  |  |  | PTC on Mesa | legacy-derived | Verify drive terminals and branch at drive
Z_STEP | MESA7I95T | TB3-14 STEP2- | DRIVE_Z | PUL- | 5V | common-anode active pulse |  |  |  |  | legacy-derived | Leave TB3-15 STEP2+ open
Z_DIR | MESA7I95T | TB3-16 DIR2- | DRIVE_Z | DIR- | 5V | common-anode |  |  |  |  | legacy-derived | Leave TB3-17 DIR2+ open
Z_STEP_DIR_COMMON | MESA7I95T | TB3-18 +5VP | DRIVE_Z | PUL+ and DIR+ | 5V | common-anode |  |  |  | PTC on Mesa | legacy-derived | Verify drive terminals and branch at drive
X_LIMIT_MIN | SENSOR_X_MIN | OUTPUT | MESA7I95T | TB6-1 INPUT0 | field input | NPN NC |  |  |  | field supply fuse | legacy-derived | TB6-3 INCOM0/1 to sensor positive
X_HOME_DEDICATED | SENSOR_X_HOME | OUTPUT | MESA7I95T | TB6-2 INPUT1 | field input | NPN NC |  |  |  | field supply fuse | legacy-derived | Wired for diagnostics; not active home source
X_LIMIT_MAX | SENSOR_X_MAX | OUTPUT | MESA7I95T | TB6-4 INPUT2 | field input | NPN NC |  |  |  | field supply fuse | legacy-derived | TB6-6 INCOM2/3 to sensor positive
TB6_INPUT3_SPARE |  |  | MESA7I95T | TB6-5 INPUT3 | field input |  |  |  |  |  | reserved | Shares TB6-6 common
Y_LIMIT_MIN | SENSOR_Y_MIN | OUTPUT | MESA7I95T | TB6-7 INPUT4 | field input | NPN NC |  |  |  | field supply fuse | legacy-derived | TB6-9 INCOM4/5 to sensor positive
Y_HOME_DEDICATED | SENSOR_Y_HOME | OUTPUT | MESA7I95T | TB6-8 INPUT5 | field input | NPN NC |  |  |  | field supply fuse | legacy-derived | Wired for diagnostics; not active home source
Y_LIMIT_MAX | SENSOR_Y_MAX | OUTPUT | MESA7I95T | TB6-10 INPUT6 | field input | NPN NC |  |  |  | field supply fuse | legacy-derived | TB6-12 INCOM6/7 to sensor positive
TB6_INPUT7_SPARE |  |  | MESA7I95T | TB6-11 INPUT7 | field input |  |  |  |  |  | reserved | Shares TB6-12 common
Z_LIMIT_MIN | SENSOR_Z_MIN | OUTPUT | MESA7I95T | TB6-13 INPUT8 | field input | NPN NC |  |  |  | field supply fuse | legacy-derived | TB6-15 INCOM8/9 to sensor positive
Z_LIMIT_MAX_HOME | SENSOR_Z_MAX | OUTPUT | MESA7I95T | TB6-14 INPUT9 | field input | NPN NC |  |  |  | field supply fuse | legacy-derived | Z+ is also the active home switch
PROBE_ACTIVE | LEGACY_Z_PROBE | SWITCH | MESA7I95T | TB6-16 INPUT10 | field input | positive switched input |  |  |  | field supply fuse | legacy-derived | TB6-18 INCOM10/11 to field 0V; verify voltage/polarity
TB6_INPUT11_SPARE |  |  | MESA7I95T | TB6-17 INPUT11 | field input |  |  |  |  |  | reserved | Shares TB6-18 common
ESTOP_OK | HARD_ESTOP_CHAIN | STATUS | MESA7I95T | TB6-19 INPUT12 | field input | closed/healthy sources positive |  |  |  | safety control fuse | legacy-derived | TB6-21 INCOM12/13 to field 0V; monitoring is not safety function
TB6_INPUT13_SPARE |  |  | MESA7I95T | TB6-20 INPUT13 | field input |  |  |  |  |  | reserved | Shares TB6-21 common
TB6_INPUT14_SPARE |  |  | MESA7I95T | TB6-22 INPUT14 | field input |  |  |  |  |  | reserved | TB6-24 INCOM14/15 allocated only after use is known
TB6_INPUT15_SPARE |  |  | MESA7I95T | TB6-23 INPUT15 | field input |  |  |  |  |  | reserved | TB6-24 INCOM14/15 allocated only after use is known
X_DRIVE_ALARM | DRIVE_X | ALM+ | MESA7I95T | TB5-1 INPUT16 | field input | open collector fault |  |  |  | field supply fuse | to-verify | AM882 ALM- to field 0V; TB5-3 INCOM16/17 to field positive
Y_DRIVE_ALARM | DRIVE_Y | ALM+ | MESA7I95T | TB5-2 INPUT17 | field input | open collector fault |  |  |  | field supply fuse | to-verify | AM882 ALM- to field 0V; shares TB5-3 common
Z_DRIVE_ALARM | DRIVE_Z | ALM+ | MESA7I95T | TB5-4 INPUT18 | field input | open collector fault |  |  |  | field supply fuse | to-verify | AM882 ALM- to field 0V; TB5-6 INCOM18/19 to field positive
TB5_INPUT19_SPARE |  |  | MESA7I95T | TB5-5 INPUT19 | field input |  |  |  |  |  | reserved | Shares TB5-6 common
TB5_INPUT20_SPARE |  |  | MESA7I95T | TB5-7 INPUT20 | field input |  |  |  |  |  | reserved | TB5-9 INCOM20/21 unallocated
TB5_INPUT21_SPARE |  |  | MESA7I95T | TB5-8 INPUT21 | field input |  |  |  |  |  | reserved | TB5-9 INCOM20/21 unallocated
TB5_INPUT22_SPARE |  |  | MESA7I95T | TB5-10 INPUT22 | field input |  |  |  |  |  | reserved | TB5-12 INCOM22/23 unallocated
TB5_INPUT23_SPARE |  |  | MESA7I95T | TB5-11 INPUT23 | field input |  |  |  |  |  | reserved | TB5-12 INCOM22/23 unallocated
VFD_RS485_A | USB_RS485 | A | HUANYANG_VFD | RS- | RS-485 | differential |  |  |  |  | legacy-derived | Verify terminal marking/polarity before power
VFD_RS485_B | USB_RS485 | B | HUANYANG_VFD | RS+ | RS-485 | differential |  |  |  |  | legacy-derived | Existing adapter is not galvanically isolated
UNKNOWN_A1_A2 |  |  |  |  |  |  |  |  |  |  | unidentified | Keep insulated; trace both ends with all power removed
UNKNOWN_B1_B2 |  |  |  |  |  |  |  |  |  |  | unidentified | Keep insulated; trace both ends with all power removed
UNKNOWN_C1_C2 |  |  |  |  |  |  |  |  |  |  | unidentified | Keep insulated; trace both ends with all power removed

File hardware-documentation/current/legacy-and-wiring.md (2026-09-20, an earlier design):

# Legacy discrepancies and wiring records

## Known errors and annotations in the legacy schematic

The paper drawing is revision 0.19 dated 2018-12-19. Treat these observations as
constraints on any migration:

1. The crossed-out **Spindle Motor Driver** block, JYQD V7.3Ei, Hall sensors,
   and spindle representation are not the installed Huanyang/induction-spindle
   system.
2. The coolant pump and its Huanyang relay connection are absent.
3. HWS1000-48 (`U1`) was replaced by a fanless supply marked 230 VAC, 5 A input,
   56 VDC output. The “not 48 V but 56” annotation refers to this replacement;
   model and DC output current remain unknown.
4. Driver-enable switch `SW4A` has an unexplained exclamation mark. Treat its
   circuit and polarity as suspect.
5. A note at N9510 pin 3 mentions two parallel electrolytic capacitors and two
   series resistors to ground without values. It may describe only a proposed
   change; inspect rather than reconstruct it.
6. Drawn `U2` (`KS400A-230S24-SCN`) was replaced by Glendale `GE-003`, marked
   230 VAC input and +5 VDC/2 A, −5 VDC/1 A, +12 VDC/2.5 A outputs.
7. The sensor voltage-conditioning network belongs to the Panther interface and
   must not be copied into the Mesa design without analysis.

## Current wiring source

Maintain a reviewable point-to-point record before producing a new KiCad
schematic. The current proposed allocation is
[`../../config/frida-mesa/wiring.csv`](../../config/frida-mesa/wiring.csv) with
fields for net, endpoints, voltage domain, logic, conductor, shielding, fuse,
status, and notes.

Use stable device identifiers and a separate device inventory. The sequence is:

1. inventory devices and terminals;
2. record every point-to-point connection;
3. review voltage domains, commons, shields, fuses, and interlocks;
4. generate or check supporting views; and
5. create the authoritative KiCad schematic from reviewed data.

WireViz may support cable and harness views but does not replace a mains/control
schematic. Track all unresolved tracing and design work in [`TODO.md`](TODO.md).

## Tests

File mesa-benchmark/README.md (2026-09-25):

# Mesa 7I95T benchmark

This directory tests HostMot2 Ethernet communication with the Mesa 7I95T at
`192.168.1.121` under sustained system load. It uses the firmware already on
the card, does not flash it, and explicitly commands all six stepgen enables
and all six isolated SSR outputs false.

> **Danger:** Connect only Ethernet and the required card power for this bench
> test. Do not connect the 7I95T step/direction, spindle, SSR, or field-I/O
> terminals to an energized machine. The configuration should not request
> motion, but it is not a safety function; a configuration, software, polarity,
> or wiring error could still actuate machinery. If the card is already wired,
> remove drive/spindle power and use a hard E-stop before running this profile.

The primary profile is `mesa-7i95t-bench-1ms.ini` with a 1 ms servo period.
The `mesa-7i95t-bench-2ms.ini` profile is the 2 ms comparison; the associated
HAL, tool table, variable, and scope files are part of those configurations.

## Run it

Apply IRQ placement after every boot, then explicitly launch the 1 ms profile
with hardware rendering:

```bash
sudo "$HOME/linuxcnc/config/thread-affinity-set.sh"
RTAPI_CPU_NUMBER=11 LIBGL_ALWAYS_SOFTWARE=0 \
    "$HOME/linuxcnc/config/linuxcnc-start.sh" \
    "$HOME/linuxcnc/mesa-benchmark/mesa-7i95t-bench-1ms.ini"
```

After LinuxCNC creates its realtime thread, verify that RTAPI created it on CPU
11. No second privileged setter call is normally required:

```bash
"$HOME/linuxcnc/config/thread-affinity-check.sh"
```

The repository-root `linuxcnc-benchmark-mesa-1ms.sh` launcher runs this check
both before and after startup. A pre-start failure is advisory because the
LinuxCNC realtime task does not exist yet; it is logged and startup continues.
The delayed post-start result is the authoritative placement check. Failure of
the privileged pre-start affinity setter still prevents startup.

Start the reproducible CPU/memory load in another terminal. It excludes the
LinuxCNC and Mesa physical cores:

```bash
./stress-test-start.sh
```

To replace an existing graphics load with ten `glxgears` instances whose
entire process tree has enforced CPU affinity, run:

```bash
./glxgears-restart.sh
```

Stop only the managed graphics load with:

```bash
./glxgears-stop.sh
```

The script sends `SIGTERM` to existing `glxgears` processes, waits for them to
exit without escalating to `SIGKILL`, and starts the replacements in the user
service `mesa-glxgears-stress.service`. The service applies CPU affinity
`0-1,3-4,6-7,9-10`. A process-local preload shim intersects affinity changes
requested by Mesa renderer workers with that safe starting mask, preventing
them from moving onto CPUs 2, 5, 8, or 11 without making Mesa's affinity call
fail. The script builds the shim privately below `diagnostic-logs/` when its
tracked source changes. It remains attached while the graphics load is
running. The stop helper uses the managed user service and reports unrelated
instances without killing them.

The target user hierarchy does not have the cgroup `cpuset` controller
delegated, so a user scope with `AllowedCPUs=` records the requested property
but does not enforce it on this host. The service affinity and preload shim are
used instead. Building the shim requires the C compiler installed on `frida`.

Override the defaults with `GLXGEARS_CPUSET`, `GLXGEARS_INSTANCES`,
`GLXGEARS_NICE`, `GLXGEARS_SERVICE_UNIT`, or `GLXGEARS_STOP_TIMEOUT`. This
script does not start, stop, or modify LinuxCNC, HAL, the diagnostic monitor,
or machine outputs.

Watch all benchmark-relevant HostMot2 error flags, read/write maxima, and the
servo-thread row in one display:

```bash
./counters-watch.sh
```

It refreshes once per second. Set `WATCH_INTERVAL` to another positive interval
or use `./counters-watch.sh --once` for a scriptable snapshot.

## Record intermittent communication errors

Use the diagnostic monitor to establish a counter baseline and append rich
snapshots when communication counters, timing maxima, NIC errors, affinity, or
the monitored workload changes:

```bash
./diagnostics-monitor.sh
```

The monitor samples once per second and writes a private, timestamped log below
`diagnostic-logs/`. Generated logs and the instance lock are ignored by Git;
only the directory placeholder and ignore rules are tracked. The monitor pins
itself and all child commands to CPUs `0-1,3-4,6-7,9-10`, away from the Mesa
and LinuxCNC physical cores.

The default mode is read-only: it does not start or stop LinuxCNC, reset HAL
state, or change affinity or network settings. A startup record contains the
absolute HAL, NIC, IRQ, process, kernel, and host baseline. Subsequent records
contain absolute values and deltas from both startup and the preceding sample.
Each complete record is bounded by matching `BEGIN_RECORD` and `END_RECORD`
lines, so an incomplete final record is easy to identify after an interruption.

Useful options include:

```bash
# Name the log and write a rich heartbeat every ten minutes.
./diagnostics-monitor.sh \
    --output mesa-long-run.log \
    --heartbeat 600

# Diagnostic-state mutation: reset only writable timing maxima after an event.
./diagnostics-monitor.sh --reset-tmax-after-event

# Safe short test: no HAL or network access, including a simulated failure.
./diagnostics-monitor.sh --mock --interval 0.1 --heartbeat 0.2 --max-samples 5
```

The reset option never clears packet-error totals, `io_error`, or other safety
state. It is disabled by default because resetting timing maxima changes the
diagnostic state. The monitor records the reset as a separate mutation record.

Follow a running log and stop a foreground monitor with `Ctrl-C`:

```bash
tail -F diagnostic-logs/mesa-long-run.log
```

For a background monitor, use the stop helper. It verifies the active lock and
process identity before sending `SIGTERM`, then waits for the monitor to append
its shutdown record and release the lock:

```bash
./diagnostics-stop.sh
```

Set another graceful-shutdown deadline with `--timeout SECONDS`. The helper
never sends `SIGKILL` and does not start, stop, or change LinuxCNC or HAL. The
monitor exits with status `130` after `SIGINT` and `143` after `SIGTERM`. Only
one monitor may run at a time; `diagnostic-logs/.monitor.lock` contains its PID
while it holds the instance lock.

Logs rotate at 64 MiB by default and retain five rotated files. Override this
with `--max-log-bytes` and `--rotated-logs`. To list complete records and their
types using standard tools:

```bash
awk '/^BEGIN_RECORD|^END_RECORD/' diagnostic-logs/mesa-long-run.log
```

For a compact summary or event timeline without printing the rich snapshots,
use the read-only report helper:

```bash
./diagnostics-report.sh --summary diagnostic-logs/mesa-long-run.log
./diagnostics-report.sh --packet-errors \
    diagnostic-logs/mesa-long-run.log
./diagnostics-report.sh --around '2026-09-24T14:31' \
    diagnostic-logs/mesa-long-run.log
./diagnostics-report.sh --timeline --format tsv \
    diagnostic-logs/mesa-long-run.log
./diagnostics-report.sh --investigation-bundle --max-lines 200 \
    diagnostic-logs/mesa-long-run.log
./diagnostics-report.sh --record '<SESSION_ID>:<SEQUENCE>' \
    --sections core,values,deltas,irq_details,realtime_task,kernel_messages \
    diagnostic-logs/mesa-long-run.log
```

Without an explicit log path, it reads the newest primary `.log` in
`diagnostic-logs/`. Reports include only complete records. `--around` accepts a
record sequence or timestamp substring and includes the adjacent records;
`--since` accepts an ISO-8601 timestamp from the same host/timezone convention.
`--investigation-bundle` emits a bounded summary plus each packet-error event
and its compact neighbors. After selecting an event, `--record` extracts only
the requested rich sections. A bare sequence is accepted only when it uniquely
identifies one complete record across the supplied logs; otherwise include the
session ID shown in timeline output. Avoid `--sections all` unless the complete
selected record is genuinely necessary.

To begin a clean diagnostic run while preserving the current run, use:

```bash
./diagnostics-restart.sh -- --output mesa-long-run.log --heartbeat 600
```

The helper gracefully stops the active monitor, moves `diagnostic-logs/` to a
UTC timestamped sibling, recreates the private log directory, starts the new
monitor under `nohup`, and verifies its lock. It does not restart LinuxCNC or
HAL. If graceful shutdown fails, it leaves the existing log directory in
place.

To explicitly reset only the writable timing maxima while LinuxCNC is running:

```bash
./counters-reset.sh --timing-maxima
```

This changes diagnostic state and can make later intervals easier to
correlate. It prints before/after values and never resets packet-error totals,
error flags, or safety state.

One-second polling cannot reliably observe millisecond-wide Boolean error
flags. The cumulative packet-error total and monotonic timing maxima are the
durable triggers; transient flags are recorded whenever a sample sees them.

The optional communication-only check is `halrun validate-7i95t.hal` when no
other HAL session is running. To exercise Wi-Fi reconnection locally, use:

```bash
WIFI_CONNECTION_NAME='<connection-name>' ./wifi-restart.sh
```

The SSH connection will drop during that test.

## Graphics options

The installed GPU is AMD Renoir/Vega `[1002:1636]`. Its correct kernel driver
is `amdgpu`, with Mesa/RadeonSI providing hardware OpenGL. `vulkan-radeon`
provides RADV for Vulkan and is not an alternative OpenGL driver for AXIS.
There is no useful replacement kernel driver for this GPU; the old `radeon`
driver does not support Renoir.

Selecting every open-source graphics option in the installer does not make
all of those drivers active: PCI matching and Mesa select the driver for the
actual GPU. The installed `xf86-video-amdgpu` package is an optional Xorg DDX
and is not used by the current Wayland session; `mesa` remains the relevant
OpenGL package.

If AXIS crashes in the current Wayland/XWayland session, first retry with
Mesa's LLVMpipe software rendering:

```bash
RTAPI_CPU_NUMBER=11 LIBGL_ALWAYS_SOFTWARE=1 \
    "$HOME/linuxcnc/config/linuxcnc-start.sh" \
    "$HOME/linuxcnc/mesa-benchmark/mesa-7i95t-bench-1ms.ini"
```

Software rendering is a diagnostic fallback and may increase latency. Another
worthwhile comparison is an Xorg desktop session using Xorg's built-in
`modesetting` driver instead of the optional `xf86-video-amdgpu` DDX; neither
choice replaces the `amdgpu` kernel driver. Zink (OpenGL over RADV/Vulkan) is
another experimental diagnostic path, not the recommended LinuxCNC setup.

## Interpret the result

Run the watcher as the same desktop user that launched LinuxCNC.

Packet totals should remain zero, Boolean error flags should remain `FALSE`,
and the servo maximum must remain below its `1,000,000 ns` period with useful
margin. This is a regression test, not proof that a completed machine is safe.

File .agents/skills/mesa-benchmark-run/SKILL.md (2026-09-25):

---
name: mesa-benchmark-run
description: Run or assess this repository's communication-only Mesa 7I95T benchmark, including affinity checks, load generation, live counters, and a concise result report. Use for benchmark execution or diagnosis, not Frida machine commissioning.
---

# Mesa benchmark run

Read `mesa-benchmark/AGENTS.md` and its `README.md` before acting.

For a new benchmark run, confirm that hazardous machine outputs are
disconnected or unpowered and that no LinuxCNC/HAL realtime session is already
active. For assessment of an existing run, identify the active profile and
remain read-only unless the user explicitly requests a state change. Do not
flash firmware, enable outputs, or substitute the Frida commissioning profile.

The local checkout is for editing. After local changes, synchronize with the
repository's required `./tools/sync-to-target.sh` wrapper; use `--dry-run` when a
preview is useful. Never replace the wrapper with ad hoc `rsync`, and never add
deletion behavior. Execute target validation over SSH from `~/linuxcnc`; local
execution is not a benchmark result.

For a new run, use the repository scripts for the workflow:

1. Have the user or administrator apply network IRQ affinity with
   `config/thread-affinity-set.sh` when root authority is required.
2. Launch the explicitly requested benchmark INI through
   `config/linuxcnc-start.sh` with `RTAPI_CPU_NUMBER=11`; default to the
   documented 1 ms profile only when the user has not requested the 2 ms
   comparison.
3. After the servo thread exists, check it with
   `config/thread-affinity-check.sh`. Do not mutate a running task unless the
   check fails and the user explicitly requests
   `thread-affinity-set.sh --repair-running-rt`.
4. Start `mesa-benchmark/stress-test-start.sh` only when sustained load is
   part of the requested run.
5. Display or capture results with
   `mesa-benchmark/counters-watch.sh`. Use `--once` for a snapshot.

For intermittent-error assessment:

- Use `counters-watch.sh --once` for a current snapshot.
- Use `diagnostics-monitor.sh` for a timestamped baseline, periodic heartbeats,
  and event records. Its default mode is read-only.
- Treat `--reset-tmax-after-event` as a diagnostic-state mutation and use it
  only when explicitly requested.
- Do not stop or restart an active monitor unless explicitly requested. When
  requested, use `diagnostics-stop.sh` so the monitor records shutdown and
  releases its instance lock cleanly.
- When the user explicitly requests a fresh run, use `diagnostics-restart.sh`
  to stop gracefully, archive the previous log directory, and start the new
  monitor. Do not invoke it merely to inspect existing evidence.
- Correlate event timestamps and baseline-relative deltas with timer, service,
  IRQ, NIC, and workload activity. One-second sampling can miss transient flags;
  cumulative totals and timing maxima are the durable triggers.

For multi-day log investigation, run parsing on `frida` and begin with
`diagnostics-report.sh --investigation-bundle --max-lines 200`. Use
`--packet-errors` for the compact event list. Only after selecting an event,
use `--record SESSION_ID:SEQUENCE --sections LIST` to extract the minimum
needed evidence. Start with `core,values,deltas`; add only relevant sections
such as `irq_details`, `realtime_task`, or `kernel_messages`. Never ingest or
print a complete multi-day log, full service inventory, journal, or ethtool
dump by default, and do not use `--sections all` without a specific reason.
Compare packet-total deltas with HostMot2 and servo maxima, NIC error/drop
deltas, sample lateness, IRQ counts and placement, realtime-task CPU,
load/pressure, and nearby kernel messages. Search narrow timestamp windows for
timer or service activity. State observed facts separately from correlations
and suspected causes.

`counters-reset.sh --timing-maxima` intentionally mutates diagnostic timing
state. Use it only when explicitly requested. It never resets communication
error totals, flags, or safety-related state.

Report the profile, test duration and load, packet-error total and flags,
HostMot2 read/write maxima, servo-thread maximum and period, CPU/IRQ placement,
the synchronized revision or diff, monitor baseline and relevant event times
when available, and any deviation from the documented procedure. Zero packet
flags and timing below the period are necessary regression criteria, not proof
of machine safety.

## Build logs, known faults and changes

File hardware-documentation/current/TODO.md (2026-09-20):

# Hardware documentation and migration checklist

This file contains every known uncertainty or task that must be resolved before
the current machine schematic and production LinuxCNC configuration can be
considered complete. Check an item only after recording the result in the
relevant topic document, the connection inventory, or the future KiCad project.

Do not inspect, disconnect or measure energized mains equipment. Record
nameplates and wiring photographs before moving conductors.

## Highest-priority architecture decisions

### Complete the replacement power-supply records

Established facts:

- The drawn TDK-Lambda HWS1000-48 (`U1`) was replaced.
- Current `U1` is fanless and marked 230 VAC, 5 A input and 56 VDC output.
- The “not 48 V but 56” paper annotation refers to this replacement rather
  than an unreasonable HWS1000-48 adjustment.
- Drawn `U2` (`KS400A-230S24-SCN`) was replaced by Glendale Electronic
  Components Pte. Ltd. model `GE-003`, marked 230 VAC input, +5 VDC/2 A,
  −5 VDC/1 A and +12 VDC/2.5 A.

- [x] Record the complete `U2` nameplate: Glendale Electronic Components Pte.
  Ltd. `GE-003`; 230 VAC input; +5 VDC/2 A, −5 VDC/1 A and +12 VDC/2.5 A
  outputs.
- [ ] Photograph the complete `U1` unit and its nameplate. Photograph the
  terminals and installed wiring of both `U1` and `U2` for the new schematic.
- [ ] Record the manufacturer and exact model of the fanless 56 VDC `U1`.
- [ ] Record `U1`'s rated DC output current/power and clarify whether its 5 A
  marking is the AC input rating, recommended fuse, or another parameter.
- [ ] With an appropriate safe procedure and loading, measure `U1` output and
  record voltage, ripple and test conditions.
- [x] Confirm the nominal `U1` voltage against the AM882 rating: 56 VDC is
  within the 20–80 VDC supply range in the AM882 manual, page 3 (68 VDC
  typical, 80 VDC maximum).
- [ ] Verify that the live DC bus remains below the AM882's 80 VDC maximum
  under high mains, deceleration/regeneration and switching transients. The
  nominal-rating comparison alone cannot establish this worst case.
- [ ] Record the GE-003 terminal pinout, output commons/returns, fusing and
  every consumer on the +5 V, −5 V and +12 V rails.
- [ ] Document the GE-003 230 VAC input wiring, fuse/protection, disconnecting
  arrangement and protective-earth connection.

### Choose the Huanyang VFD communication interface

Legacy evidence:

- Huanyang inverter: `HY02D223B`.
- Legacy settings: 19,200 baud, 8 data bits, no parity, one stop bit, address 1.
- Legacy software: `hy_vfd` opening `/dev/ttyUSB0`.
- Adapter: BerryBase `USB-RS485`, sold on Amazon under ASIN
  [`B09KV6TG3K`](https://www.amazon.de/dp/B09KV6TG3K), with a green two-screw
  RS-485 terminal. BerryBase documents the CH340C USB/UART bridge; physical
  inspection additionally identified a MAX485 ESA transceiver, capacitors,
  resistors marked `222`, `224`, `223`, and a device marked `M6`.
- Any `TTL` wording in a sales description refers to the internal
  single-ended UART side between the CH340C and MAX485. The exposed two-wire
  screw terminal is differential RS-485 and must not be treated as a TTL UART
  connection.
- There is no galvanic-isolation barrier visible. The resistor markings mean
  nominally 2.2 kΩ, 220 kΩ and 22 kΩ; none is the usual 120 Ω termination.
- One such cheap adapter failed without an identified cause.

The Mesa 7I95T can electrically support a two-wire RS-485 link on TB4 serial
channel 0. For low-speed Modbus the manual says to join TX+ to RX+, join TX− to
RX−, and disable the channel-0 termination by moving W23 to the right. This
does not settle the system design:

- The TB4 RS-422/RS-485 interface is not documented as galvanically isolated.
  It shares 7I95T logic-side ground and 5 V connections; the separately
  described field inputs/outputs are the isolated circuits.
- Mesa PktUART does not appear as `/dev/ttyUSB0`, so the existing `hy_vfd`
  command cannot simply be pointed at it.
- LinuxCNC provides Mesa PktUART Modbus frameworks, but the LinuxCNC
  documentation notes that Huanyang devices do not implement normal Modbus
  completely and suggests the dedicated `hy-vfd` driver for most HY uses.
- The installed 7I95T firmware must expose a compatible PktUART before a Mesa
  implementation can work.

Choose and document one path:

- [ ] **Recommended initial path:** replace the non-isolated BerryBase adapter with a
  reputable, galvanically isolated USB-to-RS-485 adapter and retain the proven
  `hy_vfd` software interface.
- [ ] **Possible later path:** use Mesa serial channel 0, add an appropriate
  external galvanic isolator/isolated RS-485 stage if required, and implement
  or adapt a Huanyang-compatible PktUART driver/configuration. The Ebyte
  `E810-R12` is one candidate; its local manufacturer manual is
  [`datasheets/ebyte-e810-r1x-user-manual-v1.1.pdf`](datasheets/ebyte-e810-r1x-user-manual-v1.1.pdf).
- [ ] Confirm from the VFD documentation and terminal inspection whether its
  RS-485 port itself is isolated. Do not infer this from the differential A/B
  interface.
- [ ] Decide where cable shield and any signal reference connect; avoid an
  unintended VFD-to-controller ground loop.
- [ ] Record cable type, routing, length, A/B polarity, biasing and termination.
- [x] Read `PD000`–`PD250` with a function-`0x01`-only tool and verify the
  communication settings: address 1, 19,200 bit/s, 8N1 RTU. The decoded table
  and raw CRC-checked frames are stored in the current documentation. The VFD
  returned 170 values and 81 valid unsupported replies, with no errors.
- [x] Preserve the matching handbook, including its cover, terminal tables and
  complete parameter list, as both the original scan and a searchable OCR
  derivative with plain-text sidecar. It
  differs from the project PDF: `PD035`–`PD040`, `PD067`–`PD069` and `PD079`
  are reserved; `PD089`–`PD100` and `PD109`–`PD119` are documented; and
  `PD081`–`PD085` have different descriptions. It also marks `PD184`–`PD250`
  reserved.
- [ ] Transcribe the delivered handbook's exact names, descriptions and factory
  values for `PD081`–`PD085`, `PD093`–`PD100` and `PD109`–`PD116`; do not use
  the conflicting project PDF for these fields.
- [x] Classify `PD184`–`PD250` as reserved according to the delivered
  handbook. Preserve the values returned by four reserved registers as
  forensic observations, but do not infer functions or write them.
- [ ] Replace the temporary world-writable `/dev/ttyUSB0` permissions with a
  least-privilege `uucp` group or device-specific udev rule before routine use.
- [ ] Bench-test start, stop, direction, commanded speed, feedback, timeout and
  communication-loss behavior with the spindle power stage made safe.
- [ ] Confirm that loss of communication always results in the intended safe
  state and cannot leave the spindle running unexpectedly.

### Complete the XHC pendant checksum/CRC computation

The upstream
[`xhc-whb04b-6`](https://github.com/LinuxCNC/linuxcnc/tree/master/src/hal/user_comps/xhc-whb04b-6)
protocol notes still describe byte 7 of a received report as an unresolved
checksum. For jog-wheel, rotary-switch and button-release events the observed
relationship is `checksum == random & seed`. For button-press events the
candidate expression only works reliably with seeds `0xfe` and `0xff`; the
upstream note says an equation term is missing and it is unknown whether the
algorithm is a CRC or a hand-crafted checksum.

- [x] Confirm the installed receiver's USB identity matches the upstream
  component: the kernel reports `10ce:eb93`, manufacturer `KTURT.LTD`, exactly
  matching the VID/PID compiled into LinuxCNC `xhc-whb04b-6`.
- [ ] Add an appropriate least-privilege udev rule, then run the component in
  standalone diagnostic mode (`xhc-whb04b-6 -ue`) and exercise every button,
  both selectors and the jog wheel. Matching VID/PID identifies the receiver
  but does not by itself prove identical firmware packet behavior. The first
  probe failed because the desktop user cannot currently open the USB device.
- [ ] Capture a sufficiently large set of raw USB input/output reports covering
  every button and many seed/random values, especially seeds other than
  `0xfe`/`0xff`.
- [ ] Preserve captures plus a reproducible decoder/test program in the future
  LinuxCNC workspace; exclude no samples merely because they contradict the
  current candidate formula.
- [ ] Test standard CRC-8 variants, additive/XOR/bitwise checksums and possible
  state-dependent terms against the complete capture set.
- [ ] Determine whether a wrong or unchecked checksum affects only diagnostic
  output or can cause missed/false pendant actions in normal HAL operation.
- [ ] Implement the complete computation with unit tests and submit the fix and
  protocol documentation upstream if the algorithm is resolved.

## Tool measurement and touch-off migration

Preserve the custom routines, but review and test them before attaching their
outputs to real motion. Recovered legacy behavior:

| User action or command | Legacy signal/MDI command | Function |
| --- | --- | --- |
| `M600` in G-code or MDI | remapped to `tool-job-begin.ngc` | Marks the next `M6` as the first/reference tool for a new job |
| `Fn` + `Probe-Z` | pendant `macro-9` → `halui.mdi-command-09` → `M6` | Runs the remapped automatic tool-change/tool-length routine |
| `Probe-Z` without `Fn` | `halui.mdi-command-25` | Z workpiece touch-off using the legacy 26.40 mm plate value |
| `Fn` + `Macro-10` | pendant `macro-14` → `halui.mdi-command-14` | Calls `tool-reset-offset`, which executes `M600` and then `M6` |
| `M-HOME` | `halui.mdi-command-20` | Move to legacy machine-home coordinates |
| `Safe-Z` | `halui.mdi-command-21` | Move to machine Z=0 |
| `W-HOME` | `halui.mdi-command-22` | Move to workpiece origin using the custom routine |
| No pendant mapping recovered | `halui.mdi-command-23` | X+ touch-off, 10 mm probe move, 10.00 mm plate |
| No pendant mapping recovered | `halui.mdi-command-24` | Y+ touch-off, 10 mm probe move, 10.00 mm plate |

- [ ] Copy and port `tool-change.ngc`, `tool-job-begin.ngc`,
  `tool-reset-offset.ngc`, `probe-touch-off.ngc`, `go-machine-home.ngc` and
  `go-workpiece-home.ngc` into the new LinuxCNC configuration.
- [ ] Review Machinekit-era interpreter syntax and remap configuration against
  LinuxCNC 2.9 before running any routine.
- [ ] Decide and document the normal operator sequence. The likely sequence is
  `M600` once at job start, then `M6` for the reference tool and each later
  tool, but this must be confirmed safely.
- [ ] Decide whether `Fn + Macro-10` should remain a combined reset-and-probe
  action; its label does not communicate the hazardous motion it initiates.
- [ ] Decide whether X and Y workpiece touch-off should receive pendant buttons,
  GUI controls only, or remain MDI-only.
- [ ] Verify the fixed sensor and removable workpiece probe cannot be connected
  simultaneously in an ambiguous or unsafe way if they share
  `motion.probe-input`.
- [ ] Verify probe polarity and test an already-active/stuck probe fault before
  allowing any probing motion.
- [ ] Measure the workpiece plate thicknesses; do not reuse 10.00 mm or
  26.40 mm without measurement.
- [ ] Re-establish safe travel, coarse/fine sensor positions, lowest probe
  height, feed rates and retract distance on the rebuilt controller.
- [ ] Test every routine above the table with spindle power disabled and a
  generous sacrificial clearance before normal use.
- [ ] Write a short operator procedure after validation, including recovery
  from an interrupted or failed probe cycle.

## Unidentified pre-wired cables

There are three bunches containing two cables each—six cables in total—that
were wired into the machine but could not be connected to the Panther cape.

The strongest schematic match is legacy main-schematic connector `P11`,
labelled `OUT2 P4`: pins 7/8 are `OUT4/GND`, 9/10 are `OUT5/GND`, and 11/12
are `OUT6/GND`. Those are exactly three two-conductor output pairs and were not
assigned in the recovered HAL. This is a forensic hypothesis, not an
identification; the alternatives include spare step/direction, input, probe or
alarm wiring.

- [ ] Photograph each bunch at both ends before disturbing it.
- [ ] Assign durable temporary identifiers, for example `UNKNOWN-A1/A2`,
  `UNKNOWN-B1/B2`, and `UNKNOWN-C1/C2`.
- [ ] Record conductor count, colors, shield/drain, connector, approximate
  route and where each end physically terminates.
- [ ] With all power removed and stored energy discharged, perform continuity
  tracing and check for any connection to chassis/protective earth.
- [ ] Determine whether each is a switch/sensor input, power conductor, relay
  output, probe, alarm, pendant/control, or unused spare.
- [ ] Measure or infer the intended voltage domain only after the endpoints are
  known; never discover it by trial connection to Mesa.
- [ ] Add confirmed cables to the connection inventory and future KiCad
  schematic. Mark genuinely unused conductors as spare and insulate them.

## Component identity and ratings

- [ ] Find any spindle manufacturer/model/serial marking on the body or
  connector.
- [ ] Record the spindle connector pinout, conductor colors, shield termination
  and protective-earth/bond connection.
- [ ] Verify spindle rated current, pole count/rated rpm, bearings and safe
  minimum speed from a better source than the supplied paper.
- [ ] Photograph the HY02D223B nameplate and terminals; record input ratings and
  firmware/manual revision if available.
- [x] Export all readable VFD parameters, motor data, ramps, control source and
  RS-485 settings with raw frames. Relay/pump terminal mapping remains a
  separate unresolved physical-tracing task.
- [ ] Photograph all three Leadshine labels to resolve AM882HN/AM882H suffixes.
- [ ] Photograph X, Y and Z motor nameplates to resolve `0703`/`07G3` and
  `C1824`/`C8124` discrepancies.
- [ ] Identify every 5 V, 12 V and other auxiliary supply, including ratings,
  fuses and consumers.
- [x] Record the pendant label and receiver identity. The Chinese rear label
  contains `MACH3`, `WHB04B-6`, `QC01` and `2017-05`, with no visible firmware
  version. Kernel sysfs reports the connected receiver as `10ce:eb93` and
  `KTURT.LTD`; `lsusb` is not currently installed.

## Sensors, probes and motion

- [x] Count and identify all eight physical sensors: X− no. 4, X home no. 5,
  X+ no. 6, Y+ no. 3, Y home, Y−, Z− no. 8 and Z+ no. 7. There is no
  separate Z-home sensor.
- [x] Confirm that the two sensors omitted from active legacy HAL were the
  dedicated X-home and Y-home sensors, not spares.
- [ ] Record the visible number markings for `YH` and `Y-`, then trace every
  sensor cable, supply and Mesa destination and verify NPN-NC behavior.
- [ ] Identify the fixed tool-height sensor and document travel, overtravel,
  repeatability, polarity and safe coordinates.
- [ ] Identify the workpiece probe/plate and document its cable and dimensions.
- [ ] Measure physical axis travel, hard stops, screw pitch, coupling ratio,
  microstep setting and resulting steps/mm.
- [ ] Verify motion directions and identify physical X−/X+, Y−/Y+ and Z−/Z+.
- [ ] Confirm whether legacy software spans X 510 mm, Y 477 mm and Z 130.5 mm
  remain safe usable travel.
- [ ] Record table size, spindle-to-table envelope, gantry clearance, spindle
  mount dimensions and machine datum orientation.

## Pumps, switching, interlocks and protection

- [ ] Identify the spindle water pump's model, voltage/current, flow/head and
  fuse. Check whether its conductor is on `FA(MB)` or `FC(MB)` and record all
  three physical relay-terminal labels and wire positions.
- [ ] Resolve the terminal-documentation mismatch: the table lists `FA(MB)`,
  `FB(MA)`, `FC(MA)`, while the basic diagram orders `FC(MA)`, `FA(MB)`,
  `FB(MA)`. Verify with power removed which three terminals form the inferred
  `FA/FB/FC` changeover contact, identify common/NO/NC, and confirm whether the
  applicable contact rating is 3 A at 250 VAC and/or 3 A at 30 VDC.
- [ ] Reconcile `PD130=1` and pump settings `PD133`–`PD139` with the actual
  switching circuit. `PD050`–`PD053` currently do not assign auxiliary-pump
  function 25 to any of the four documented multifunction outputs.
- [ ] Record hose size, reservoir/radiator arrangement, normal flow and any
  flow/temperature interlock.
- [ ] Trace the reason for the `SW4A` exclamation mark and verify driver-enable
  polarity and fail-safe behavior.
- [ ] Inspect whether the N9510 capacitor/resistor annotation was implemented;
  record values and purpose if present.
- [ ] Identify the vacuum relay/contactor and the separate vacuum pump/load;
  clarify what each of the two front-panel switches controls.
- [ ] Trace all six front-panel switches and record terminals, voltage, load
  and protection.
- [ ] Document emergency-stop devices, safety relay/contactor chain, reset
  behavior and which energy sources are removed.
- [ ] Record every fuse/breaker, contactor, relay, filter, braking resistor,
  protective-earth and shield connection.

## Documentation deliverables

- [ ] Create the device inventory with stable reference identifiers.
- [x] Create the initial point-to-point connection CSV described in
  [`legacy-and-wiring.md`](legacy-and-wiring.md); complete its unverified fields
  during physical tracing.
- [ ] Record every resolved checklist result in the relevant topic document.
- [ ] Create and review the corrected KiCad schematic.
- [ ] Generate a PDF schematic and wiring/terminal schedules.
- [ ] Create a Mesa I/O allocation table and cross-reference it to HAL signal
  names and KiCad net names.
- [ ] Create commissioning test sheets for power, E-stop, limits, drives,
  probing, spindle communication, coolant and vacuum equipment.

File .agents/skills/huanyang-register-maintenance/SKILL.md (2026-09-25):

---
name: huanyang-register-maintenance
description: Capture, compare, validate, or render the Huanyang HY02D223B read-only register records in this repository. Use for VFD parameter-backup maintenance, not VFD writes or spindle control.
---

# Huanyang register maintenance

Read `hardware-documentation/current/AGENTS.md` and the VFD topic linked from
`hardware-documentation/current/README.md`.

Preserve these boundaries:

- The local checkout is for editing. Synchronize intended changes to
  `frida@frida:~/linuxcnc/` without `.git` or `--delete`, then run repository
  tools over SSH from `~/linuxcnc`. Treat generated files
  returned to the local checkout as pending evidence that still needs review.
- Use `hardware-documentation/current/tools/read-huanyang-vfd.py` for live
  captures. It constructs only Huanyang function `0x01` read requests.
- Never use a general VFD control loop or register-write command as a forensic
  capture substitute.
- A live capture requires explicit user intent, a verified serial device, and a
  safely stopped/unpowered spindle power stage. Do not infer authorization to
  access hardware from a documentation or comparison request.
- Store raw JSON as the primary evidence. Do not hand-edit captured frames or
  values.
- Render Markdown with `python3 hardware-documentation/current/tools/render-huanyang-register-table.py INPUT_JSON OUTPUT_MD`
  and review the resulting diff.
- Treat OCR and family manuals as aids. Physical identity and the matching
  delivered handbook take precedence; retain conflicts and unknown/reserved
  values instead of guessing.

For comparisons, distinguish raw-value changes, capture errors, unsupported
replies, and documentation-only decoding changes. Report the input files,
capture metadata, changed parameters, and whether the generated Markdown is in
sync with its JSON source.

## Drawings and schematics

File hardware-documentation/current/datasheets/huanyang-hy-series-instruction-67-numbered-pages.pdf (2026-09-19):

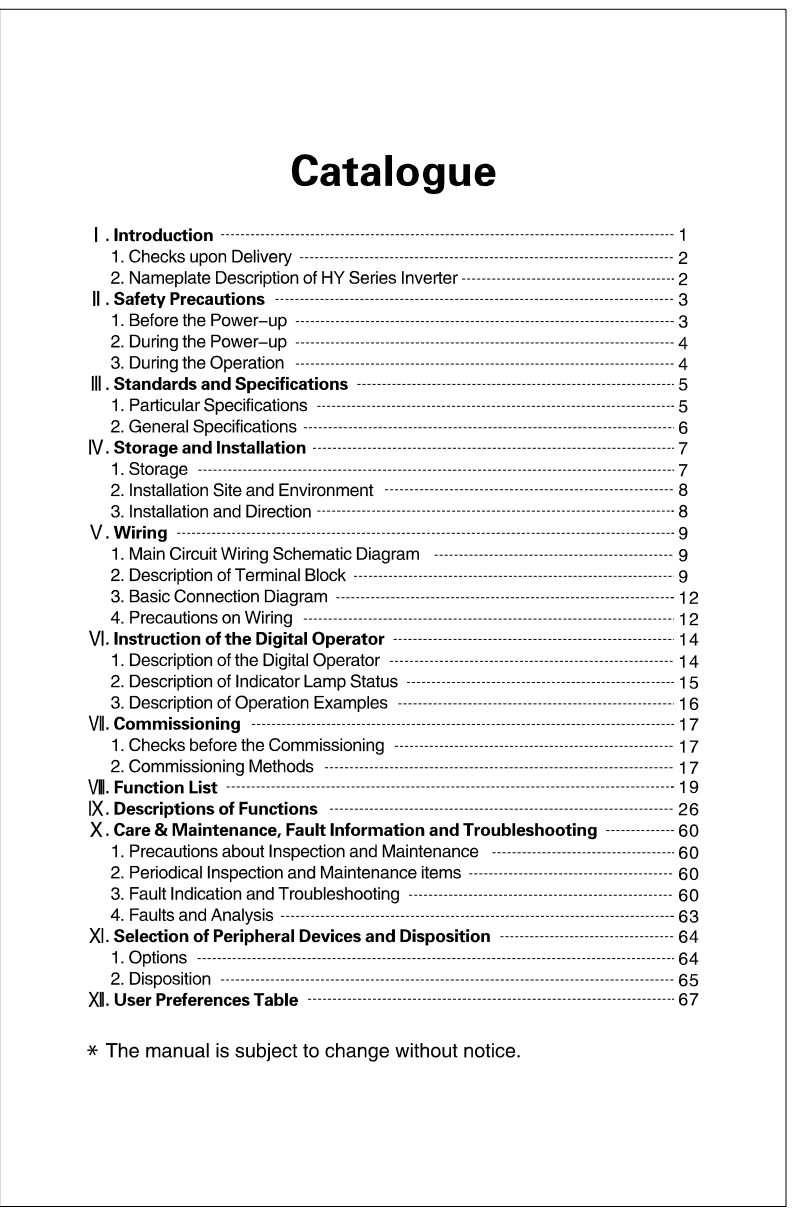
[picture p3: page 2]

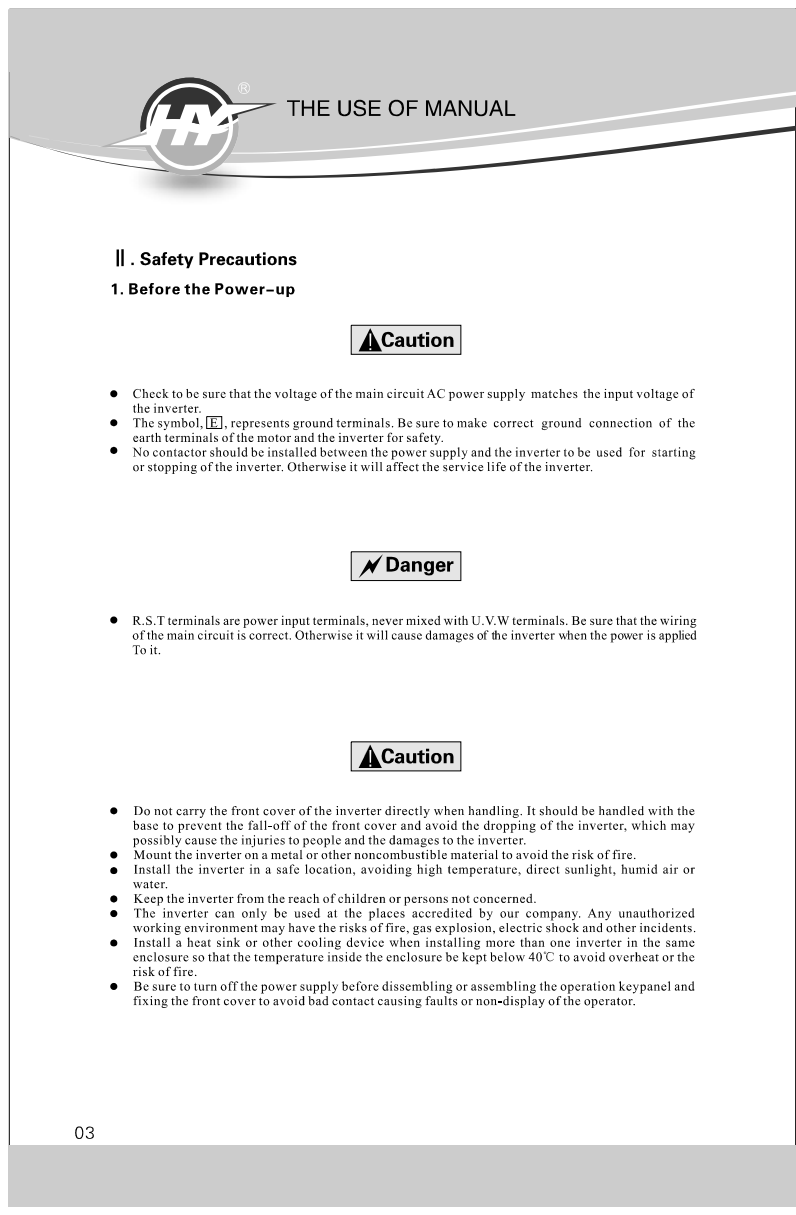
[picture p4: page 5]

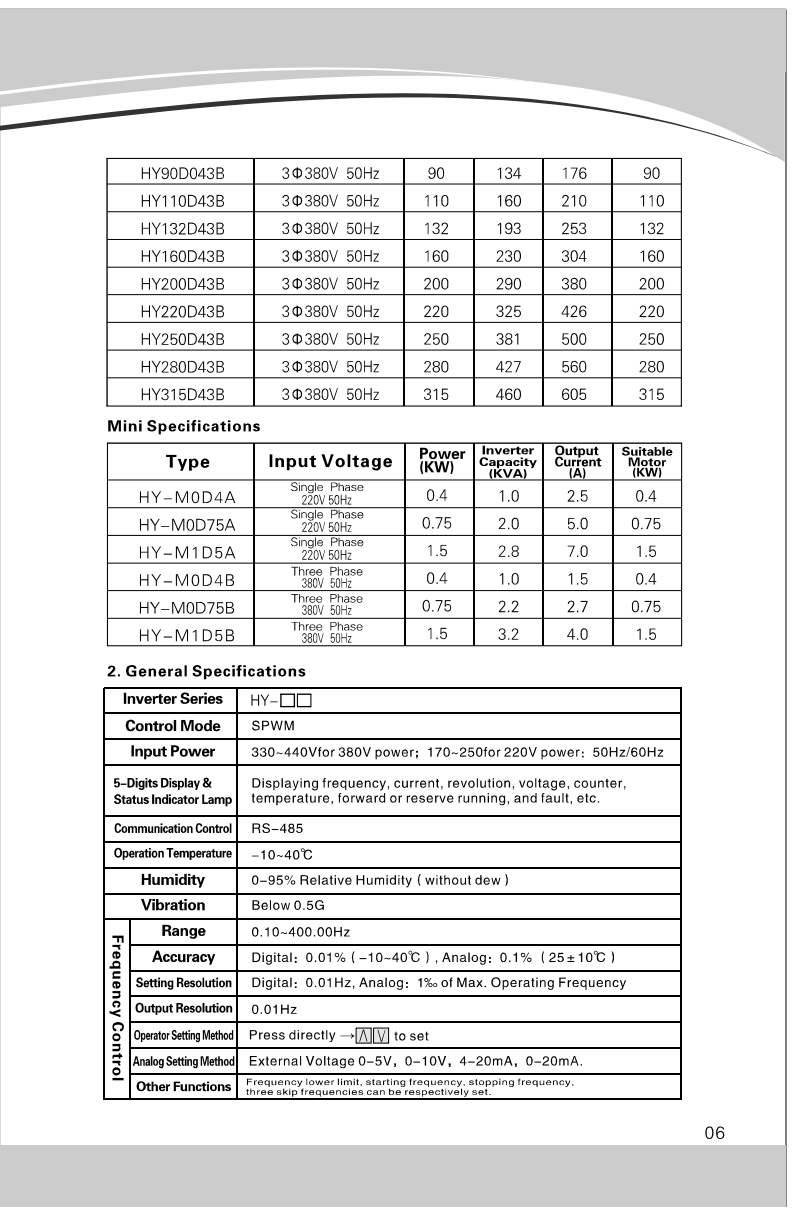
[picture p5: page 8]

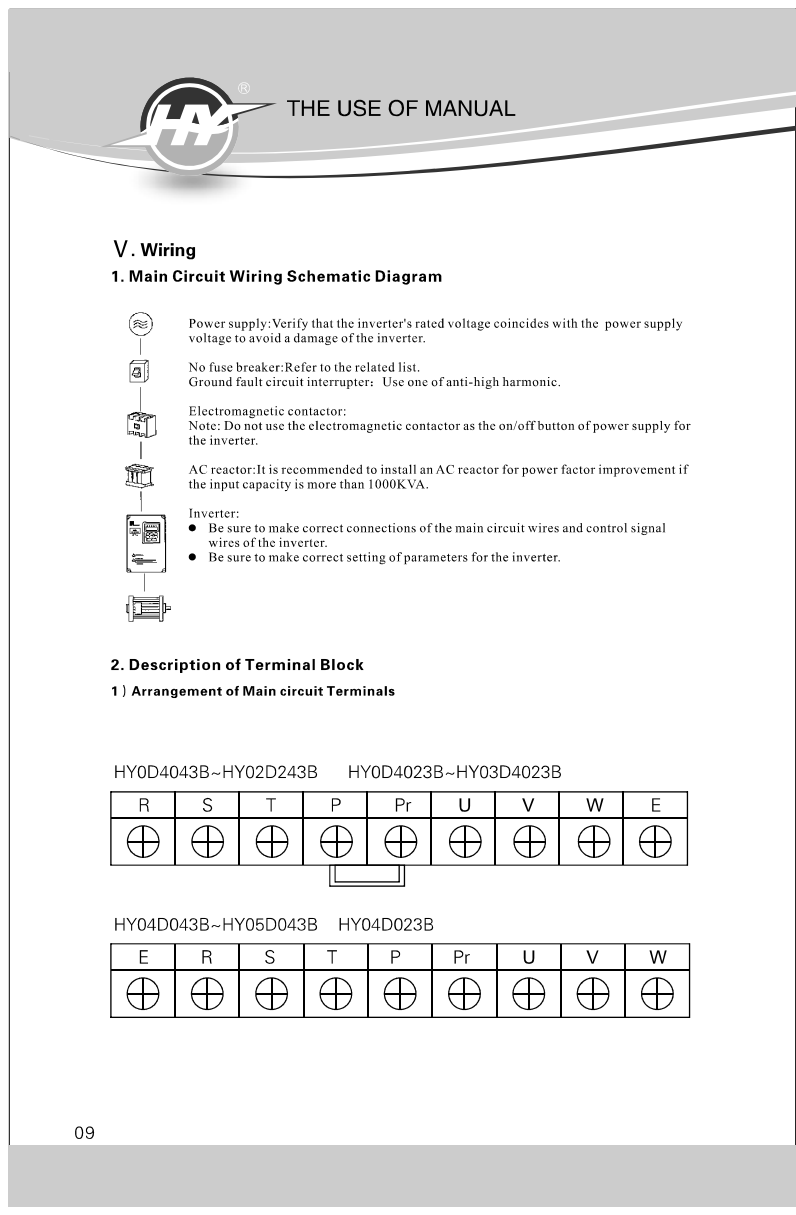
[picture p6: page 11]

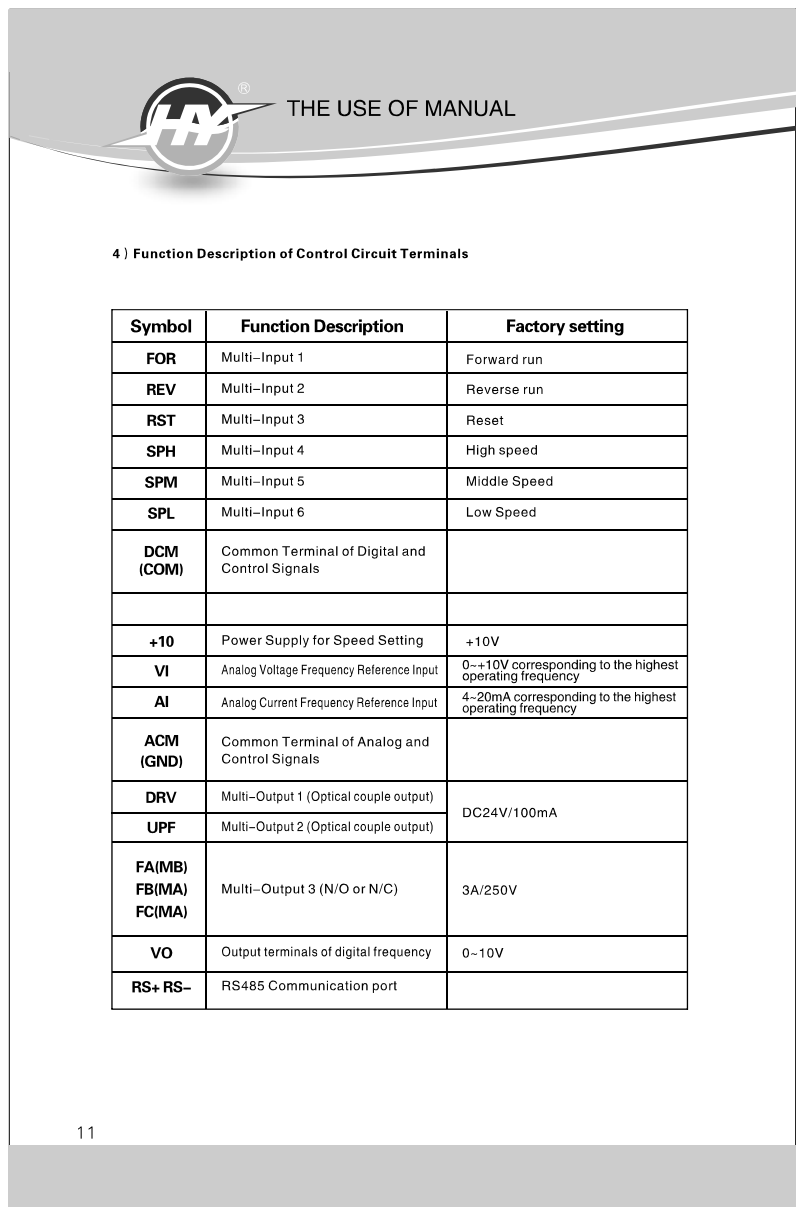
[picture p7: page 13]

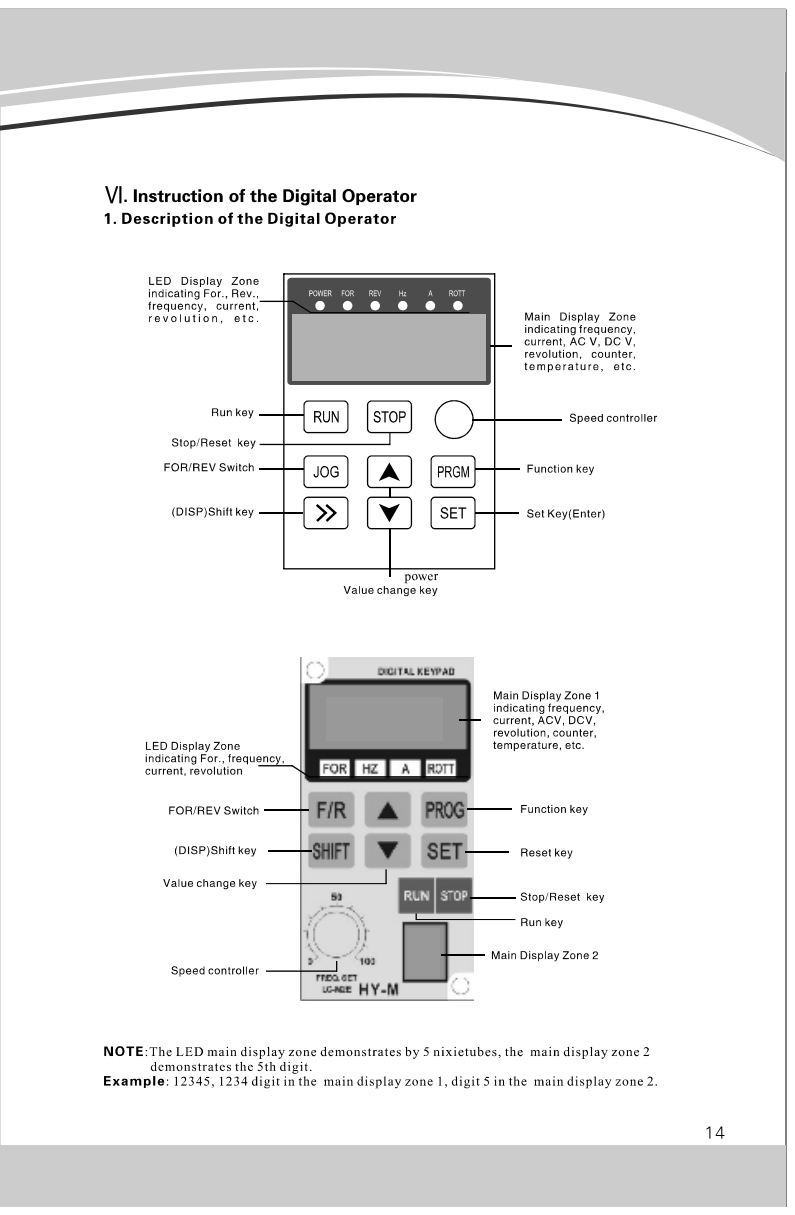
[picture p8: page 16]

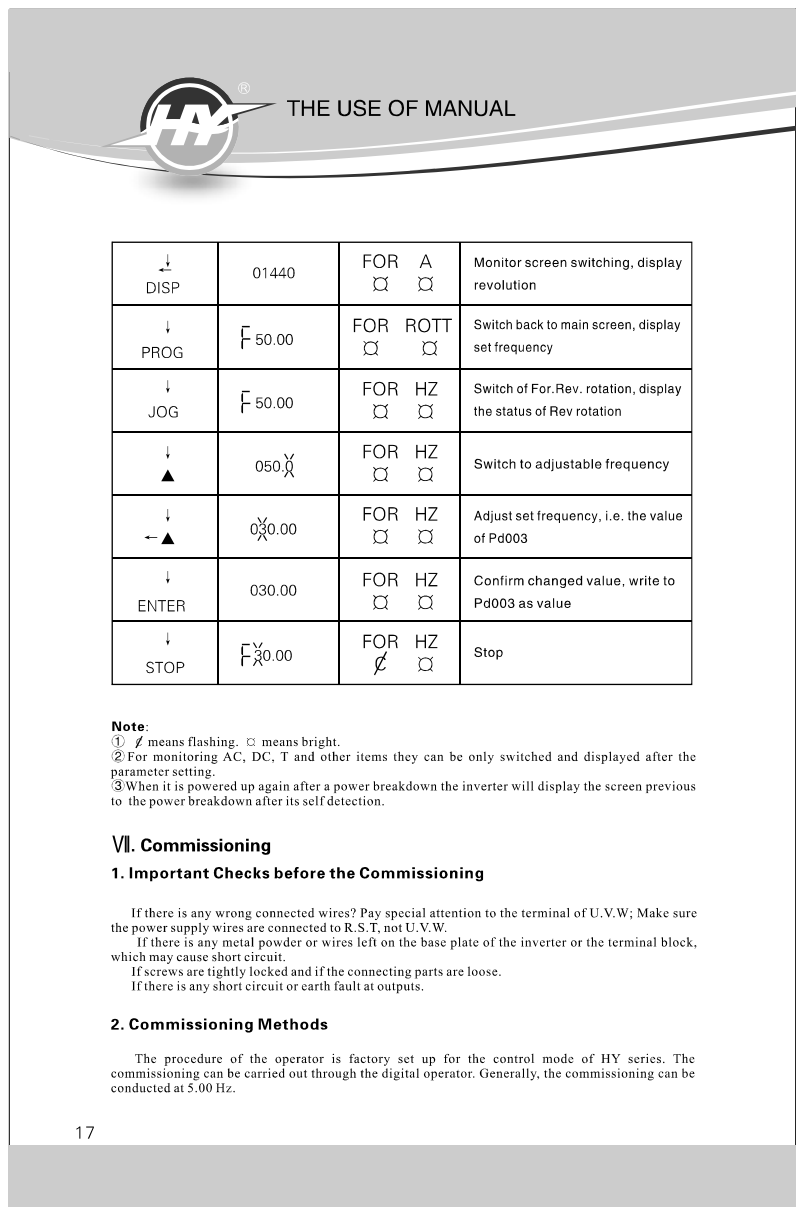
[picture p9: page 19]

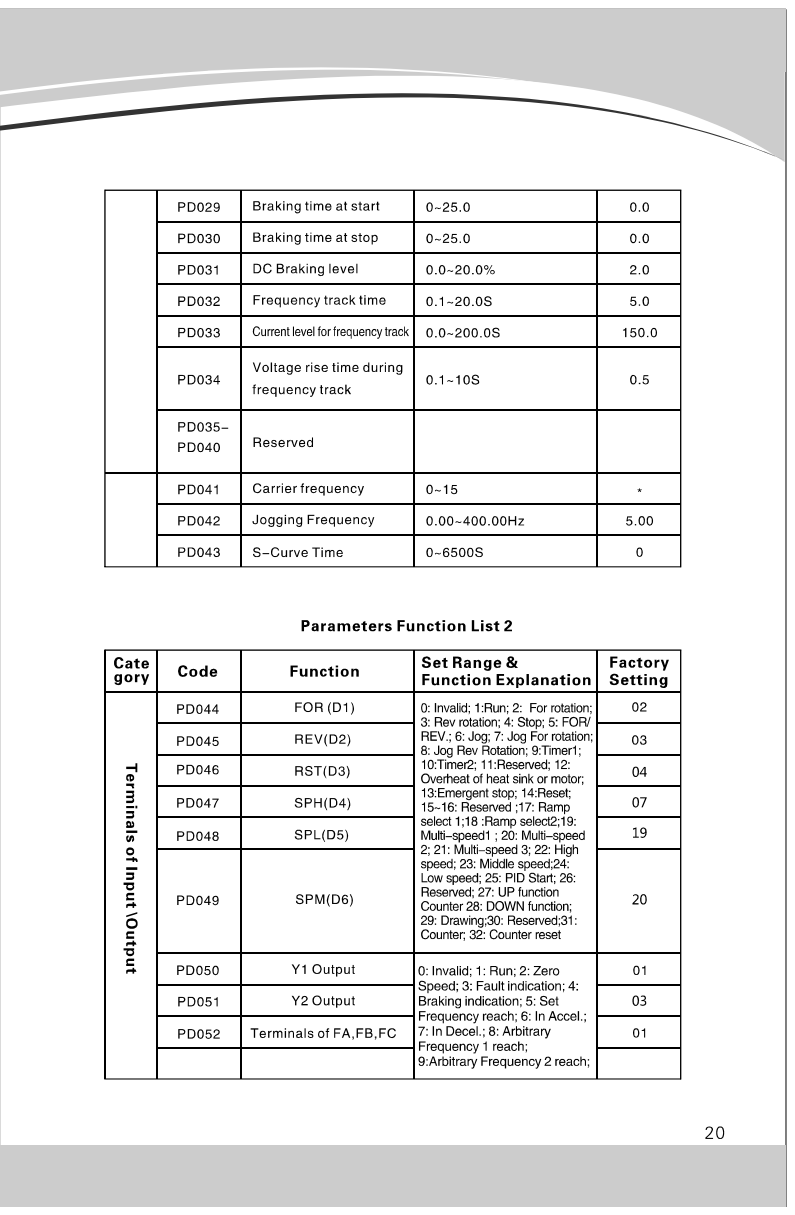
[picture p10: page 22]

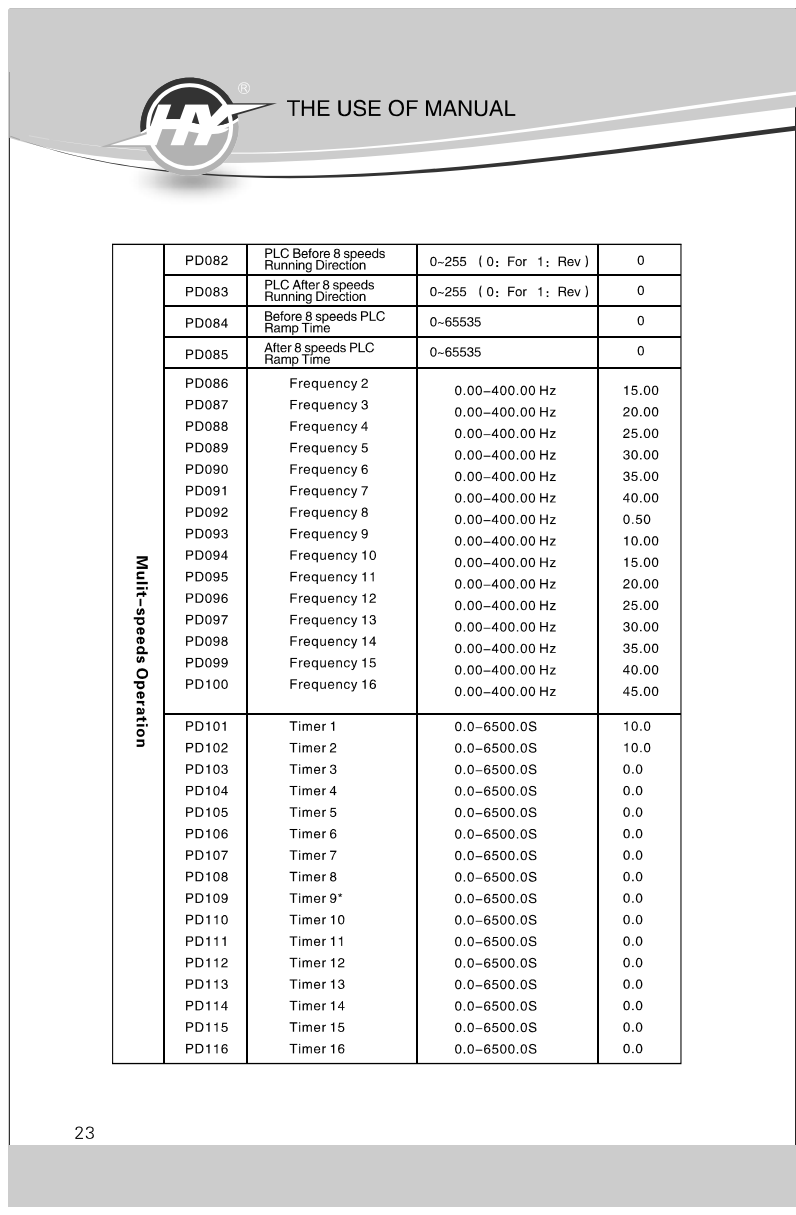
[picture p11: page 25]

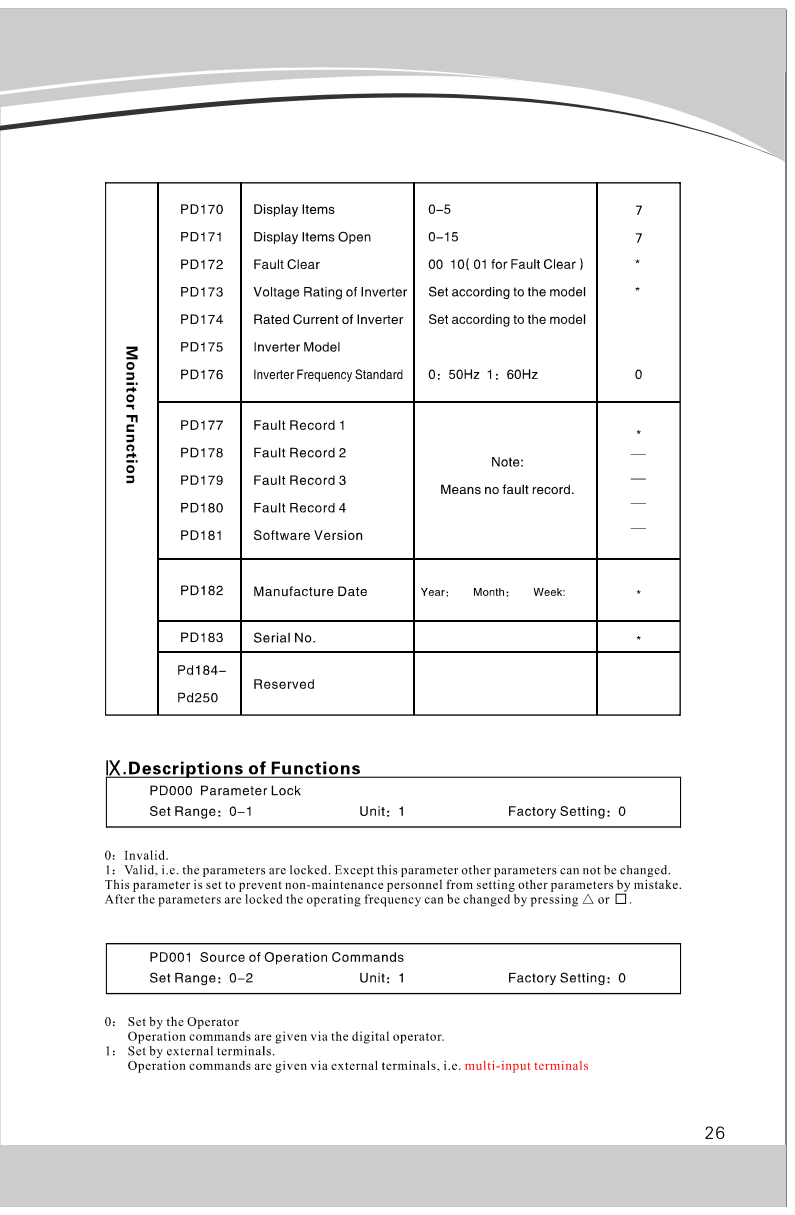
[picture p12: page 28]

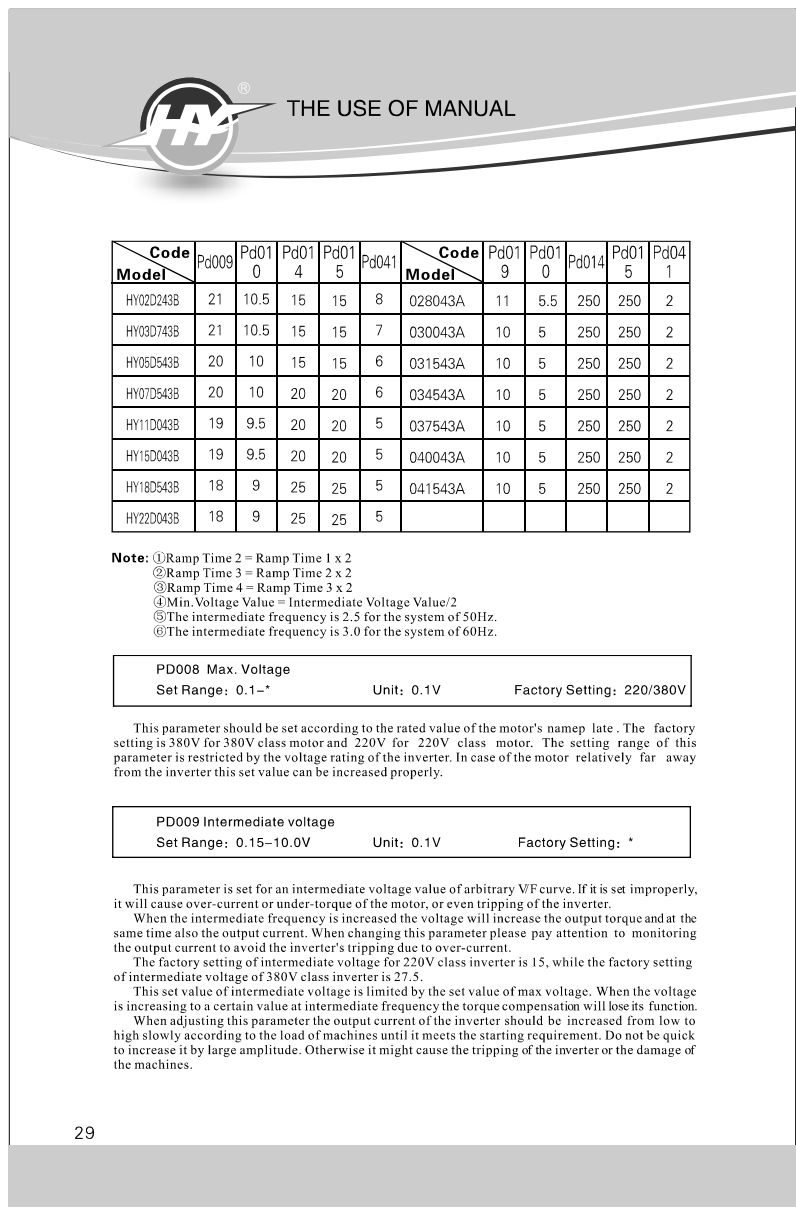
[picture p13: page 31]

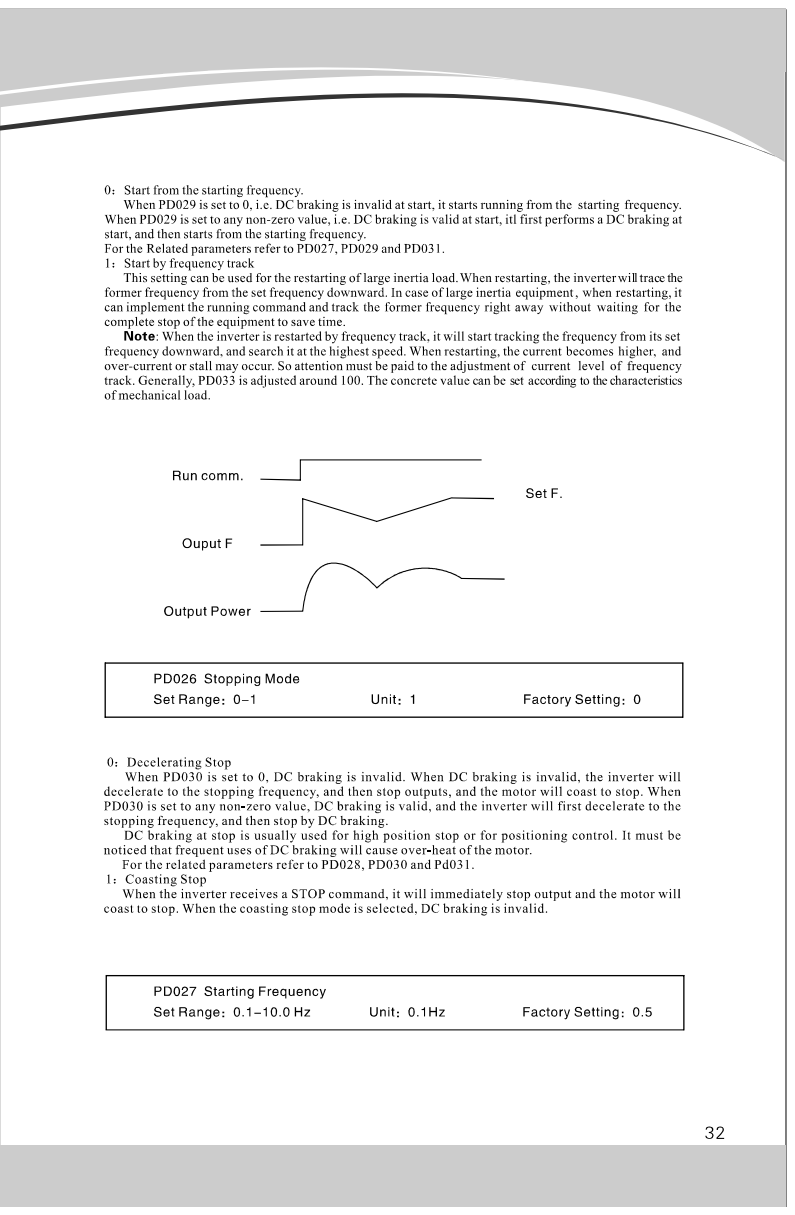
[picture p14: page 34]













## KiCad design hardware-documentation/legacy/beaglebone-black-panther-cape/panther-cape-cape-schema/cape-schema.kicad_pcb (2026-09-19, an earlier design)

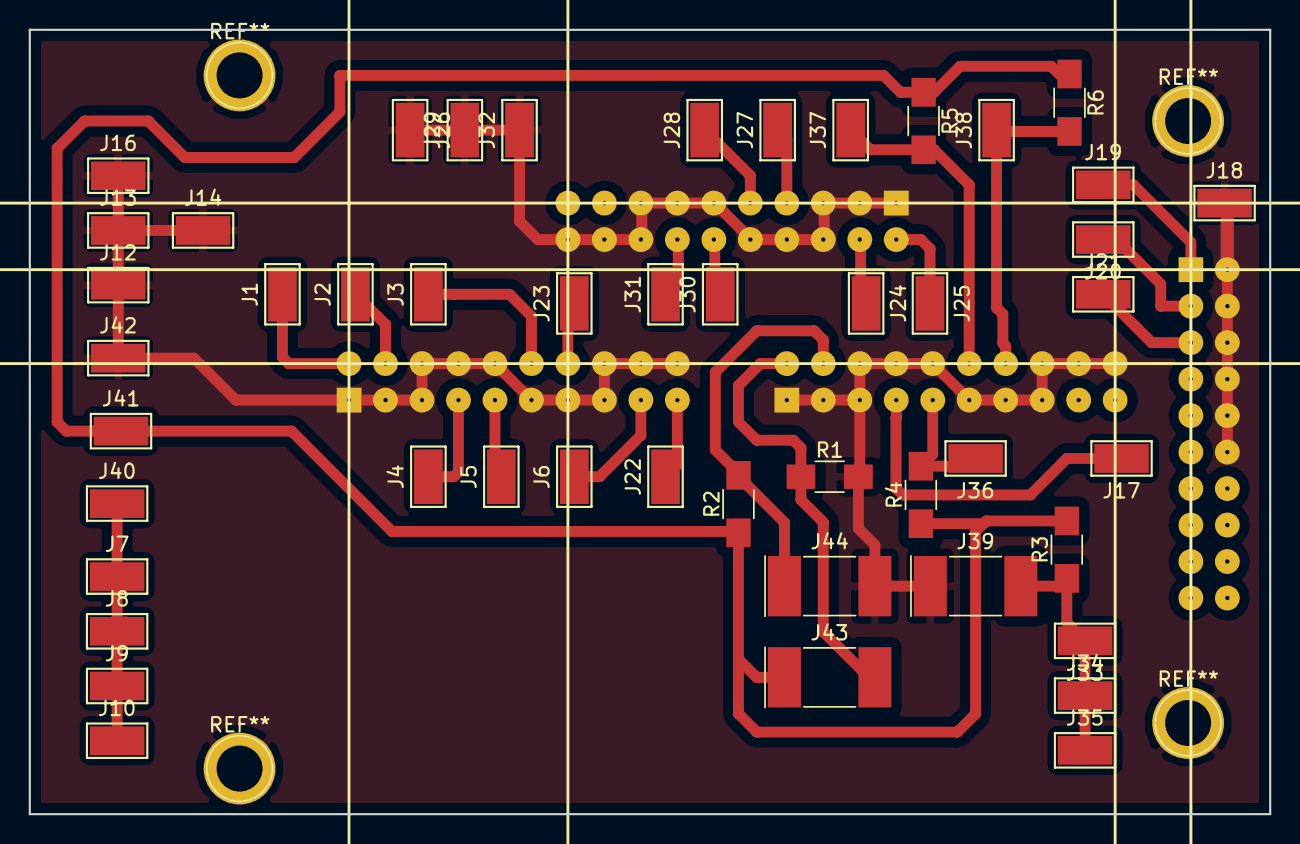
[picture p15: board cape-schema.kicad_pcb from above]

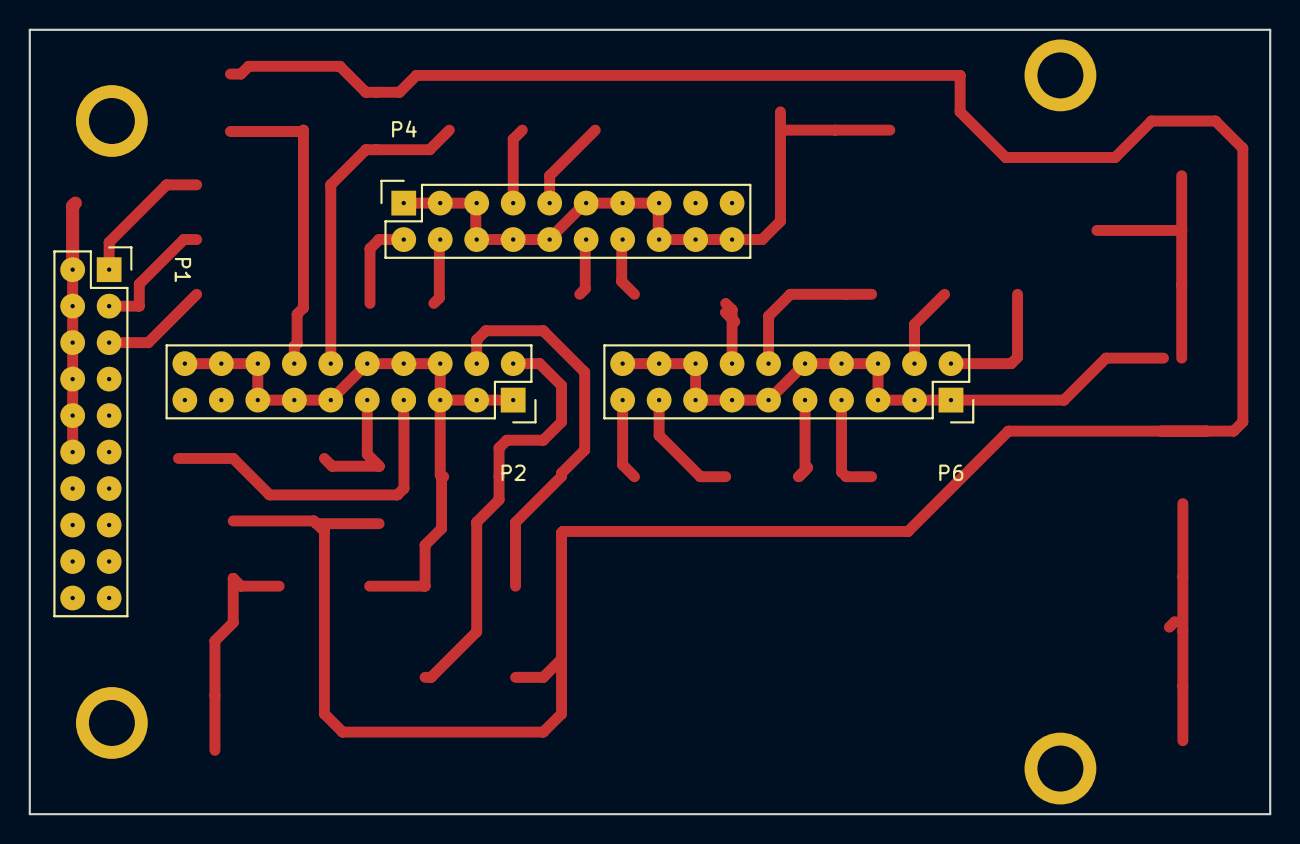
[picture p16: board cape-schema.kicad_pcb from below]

Board: 2 copper layers, 86.4 x 54.6 mm, 52 parts (4 on the bottom side), 27 nets.

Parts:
J1: X_LIMIT_MIN; Test_Point_Keystone_5019_Minature
J2: X_LIMIT_MAX; Test_Point_Keystone_5019_Minature
J3: X_HOME; Test_Point_Keystone_5019_Minature
J4: Y_LIMIT_MIN; Test_Point_Keystone_5019_Minature
J5: Y_LIMIT_MAX; Test_Point_Keystone_5019_Minature
J6: Y_HOME; Test_Point_Keystone_5019_Minature
J7, J8, J9, J10, J40: SENSORS+; Test_Point_Keystone_5019_Minature
J12, J13, J14, J16: SENSORS-; Test_Point_Keystone_5019_Minature
J17: SPINDLE_FEEDBACK; Test_Point_Keystone_5019_Minature
J18: SPINDLE_SIGNAL-; Test_Point_Keystone_5019_Minature
J19: SPINDLE_ENABLE; Test_Point_Keystone_5019_Minature
J20: SPINDLE_DIR; Test_Point_Keystone_5019_Minature
J21: SPINDLE_RPM; Test_Point_Keystone_5019_Minature
J22: Z_LIMIT_MIN; Test_Point_Keystone_5019_Minature
J23: Z_LIMIT_MAX; Test_Point_Keystone_5019_Minature
J24: X_DIR; Test_Point_Keystone_5019_Minature
J25: X_STEP; Test_Point_Keystone_5019_Minature
J26, J29, J32: DRIVER_SIGNALS-; Test_Point_Keystone_5019_Minature
J27: Y_STEP; Test_Point_Keystone_5019_Minature
J28: Y_DIR; Test_Point_Keystone_5019_Minature
J30: Z_STEP; Test_Point_Keystone_5019_Minature
J31: Z_DIR; Test_Point_Keystone_5019_Minature
J33, J34, J35: DRIVER_ENABLE; Test_Point_Keystone_5019_Minature
J36: X_ALARM; Test_Point_Keystone_5019_Minature
J37: Y_ALARM; Test_Point_Keystone_5019_Minature
J38: Z_ALARM; Test_Point_Keystone_5019_Minature
J39: DRIVER_ENABLE_SWITCH; Crystal_SMD_MicroCrystal_CC1V-T1A-2pin_8.0x3.7mm
J41: PC+; Test_Point_Keystone_5019_Minature
J42: GND; Test_Point_Keystone_5019_Minature
J43: EMERGENCY_STOP_SWITCH; Crystal_SMD_MicroCrystal_CC1V-T1A-2pin_8.0x3.7mm
J44: Z_PROBE_LIMIT_SWITCH; Crystal_SMD_MicroCrystal_CC1V-T1A-2pin_8.0x3.7mm
P1: OUT2 P4; Socket_Strip_Straight_2x10
P2: IN2 P2; Socket_Strip_Straight_2x10
P4: OUT1 P3; Socket_Strip_Straight_2x10
P6: IN1 P1; Socket_Strip_Straight_2x10
R1: 10k; R_1206_HandSoldering
R2: 20k; R_1206_HandSoldering
R3: 470R; R_1206_HandSoldering
R4, R5, R6: 1k; R_1206_HandSoldering

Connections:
DRIVER_ENABLE: J33.1, J34.1, J35.1, J39.2, R3.1
DRIVER_SIGNALS-: J12.1, J13.1, J14.1, J16.1, J18.1, J26.1, J29.1, J32.1, J39.1, J42.1, J44.2, P1.2, P1.4, P1.6, P1.8, P1.10, P1.12, P2.1, P2.3, P2.5, P2.6, P2.8, P2.10, P2.11, P2.13, P2.15, P2.16, P2.18, P2.20, P4.1, P4.3, P4.5, P4.6, P4.8, P4.10, P4.11, P4.13, P4.15, P4.16, P4.18, P4.20, P6.1, P6.3, P6.5, P6.6, P6.8, P6.10, P6.11, P6.13, P6.15, P6.16, P6.18, P6.20, R1.2
EMERGENCY_STOP: J43.2, P2.2, R1.1
PC+: J41.1, J43.1, R2.1, R3.2, R4.1, R5.1, R6.1
SENSORS+: J7.1, J8.1, J9.1, J10.1, J40.1
SPINDLE_DIR: J20.1, P1.3
SPINDLE_ENABLE: J19.1, P1.1
SPINDLE_RPM: J21.1, P1.5
SPINDLE_RPM_FEEDBACK: J17.1, P2.7
X_ALARM: J36.1, P2.9, R4.2
X_DIR: J24.1, P4.4
X_HOME: J3.1, P6.12
X_LIMIT_MAX: J2.1, P6.4
X_LIMIT_MIN: J1.1, P6.2
X_STEP: J25.1, P4.2
Y_ALARM: J37.1, P2.12, R5.2
Y_DIR: J28.1, P4.9
Y_HOME: J6.1, P6.17
Y_LIMIT_MAX: J5.1, P6.9
Y_LIMIT_MIN: J4.1, P6.7
Y_STEP: J27.1, P4.7
Z_ALARM: J38.1, P2.14, R6.2
Z_DIR: J31.1, P4.14
Z_LIMIT_MAX: J23.1, P6.14
Z_LIMIT_MIN: J22.1, P6.19
Z_PROBE: J44.1, P2.4, R2.2
Z_STEP: J30.1, P4.12

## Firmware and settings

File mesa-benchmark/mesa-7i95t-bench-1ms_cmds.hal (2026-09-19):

# Sat Sep 19 08:50:56 CEST 2026
#
# This file:    ./mesa-7i95t-bench-1ms_cmds.hal
# Created by:   /usr/share/linuxcnc/hallib/basic_sim.tcl
# With options: 
# From inifile: ./mesa-7i95t-bench-1ms.ini
# Halfiles:     LIB:basic_sim.tcl mesa-7i95t-bench-1ms.hal
#
# This file contains the hal commands produced by basic_sim.tcl
# (and any hal commands executed prior to its execution).
# ------------------------------------------------------------------
# To use ./mesa-7i95t-bench-1ms_cmds.hal in the original inifile (or a copy),
# edit to change:
#     [HAL]
#     HALFILE = LIB:basic_sim.tcl parameters
# to:
#     [HAL]
#     HALFILE = ./mesa-7i95t-bench-1ms_cmds.hal
#
# Notes:
#  1) Inifile Variables substitutions specified in the inifile
#     and interpreted by halcmd are automatically substituted
#     in the created halfile (./mesa-7i95t-bench-1ms_cmds.hal).
#  2) Input pins connected to a signal with no writer are
#     not included in the setp listings herein so must be added
#     manually
#

# user space components
loadusr -W hal_manualtoolchange

# components
#preloaded module: loadrt tpmod 
#preloaded module: loadrt homemod 
loadrt trivkins coordinates=XYZ 
loadrt motmod base_period_nsec=0 servo_period_nsec=1000000 num_joints=3 
#loadrt __servo-thread  (not loaded by loadrt, no args saved)
loadrt pid names=J0_pid,J1_pid,J2_pid 
loadrt mux2 names=J0_mux,J1_mux,J2_mux 
loadrt ddt names=J0_vel,J0_accel,J1_vel,J1_accel,J2_vel,J2_accel 
loadrt hypot names=hyp_xy,hyp_xyz 
loadrt sim_home_switch names=J0_switch,J1_switch,J2_switch 
loadrt sim_spindle names=sim_spindle 
loadrt limit2 names=limit_speed 
loadrt lowpass names=spindle_mass 
loadrt near names=near_speed 
loadrt scale names=rpm_rps 
# pin aliases
# param aliases
# signals
# nets
net J0:acc J0_accel.out
net J0:enable joint.0.amp-enable-out => J0_pid.enable
net J0:homesw J0_switch.home-sw => joint.0.home-sw-in
net J0:on-pos J0_pid.output => J0_mux.in1
net J0:pos-cmd joint.0.motor-pos-cmd => J0_pid.command
net J0:pos-fb J0_mux.out => J0_mux.in0 J0_switch.cur-pos J0_vel.in joint.0.motor-pos-fb
net J0:vel J0_vel.out => J0_accel.in hyp_xy.in0 hyp_xyz.in0
net J1:acc J1_accel.out
net J1:enable joint.1.amp-enable-out => J1_pid.enable
net J1:homesw J1_switch.home-sw => joint.1.home-sw-in
net J1:on-pos J1_pid.output => J1_mux.in1
net J1:pos-cmd joint.1.motor-pos-cmd => J1_pid.command
net J1:pos-fb J1_mux.out => J1_mux.in0 J1_switch.cur-pos J1_vel.in joint.1.motor-pos-fb
net J1:vel J1_vel.out => J1_accel.in hyp_xy.in1 hyp_xyz.in1
net J2:acc J2_accel.out
net J2:enable joint.2.amp-enable-out => J2_pid.enable
net J2:homesw J2_switch.home-sw => joint.2.home-sw-in
net J2:on-pos J2_pid.output => J2_mux.in1
net J2:pos-cmd joint.2.motor-pos-cmd => J2_pid.command
net J2:pos-fb J2_mux.out => J2_mux.in0 J2_switch.cur-pos J2_vel.in joint.2.motor-pos-fb
net J2:vel J2_vel.out => J2_accel.in hyp_xyz.in2
net estop:loop iocontrol.0.user-enable-out => iocontrol.0.emc-enable-in
net sample:enable motion.motion-enabled => J0_mux.sel J1_mux.sel J2_mux.sel
net spindle-at-speed near_speed.out => spindle.0.at-speed
net spindle-index-enable sim_spindle.index-enable <=> spindle.0.index-enable
net spindle-orient spindle.0.orient => spindle.0.is-oriented
net spindle-pos sim_spindle.position-fb => spindle.0.revs
net spindle-rpm-filtered spindle_mass.out => near_speed.in2 rpm_rps.in
net spindle-rps-filtered rpm_rps.out => spindle.0.speed-in
net spindle-speed-cmd spindle.0.speed-out => limit_speed.in near_speed.in1
net spindle-speed-limited limit_speed.out => sim_spindle.velocity-cmd spindle_mass.in
net tool:change iocontrol.0.tool-change => hal_manualtoolchange.change
net tool:changed hal_manualtoolchange.changed => iocontrol.0.tool-changed
net tool:prep-loop iocontrol.0.tool-prepare => iocontrol.0.tool-prepared
net tool:prep-number iocontrol.0.tool-prep-number => hal_manualtoolchange.number
net xy:vel hyp_xy.out
net xyz:vel hyp_xyz.out
# parameter values
setp J0_accel.tmax                  0
setp J0_mux.tmax                    0
setp J0_pid.do-pid-calcs.tmax       0
setp J0_switch.tmax                 0
setp J0_vel.tmax                    0
setp J1_accel.tmax                  0
setp J1_mux.tmax                    0
setp J1_pid.do-pid-calcs.tmax       0
setp J1_switch.tmax                 0
setp J1_vel.tmax                    0
setp J2_accel.tmax                  0
setp J2_mux.tmax                    0
setp J2_pid.do-pid-calcs.tmax       0
setp J2_switch.tmax                 0
setp J2_vel.tmax                    0
setp hyp_xy.tmax                    0
setp hyp_xyz.tmax                   0
setp limit_speed.tmax               0
setp motion-command-handler.tmax    0
setp motion-controller.tmax         0
setp near_speed.difference          10
setp near_speed.scale               1.1
setp near_speed.tmax                0
setp rpm_rps.tmax                   0
setp servo-thread.tmax              0
setp sim_spindle.scale              0.01666667
setp sim_spindle.tmax               0
setp spindle_mass.gain              0.07
setp spindle_mass.tmax              0
# Note: ALL unconnected pins follow
#       (includes pins using default with no explicit setp command)
setp J0_pid.Dgain                   0
setp J0_pid.FF0                     1
setp J0_pid.FF1                     0
setp J0_pid.FF2                     0
setp J0_pid.FF3                     0
setp J0_pid.Igain                   0
setp J0_pid.Pgain                   0
setp J0_pid.bias                    0
setp J0_pid.command-deriv           0
setp J0_pid.deadband                0
setp J0_pid.error-previous-target   TRUE
setp J0_pid.feedback                0
setp J0_pid.feedback-deriv          0
setp J0_pid.index-enable            FALSE
setp J0_pid.maxcmdD                 0
setp J0_pid.maxcmdDD                0
setp J0_pid.maxcmdDDD               0
setp J0_pid.maxerror                0
setp J0_pid.maxerrorD               0
setp J0_pid.maxerrorI               0
setp J0_pid.maxoutput               0
setp J0_pid.tune-cycles             0x00000032
setp J0_pid.tune-effort             0.5
setp J0_pid.tune-mode               FALSE
setp J0_pid.tune-start              FALSE
setp J0_pid.tune-type               0x00000000
setp J0_switch.home-pos             1
setp J0_switch.hysteresis           0.1
setp J0_switch.index-delay-ms       10
setp J0_switch.index-enable         FALSE
setp J1_pid.Dgain                   0
setp J1_pid.FF0                     1
setp J1_pid.FF1                     0
setp J1_pid.FF2                     0
setp J1_pid.FF3                     0
setp J1_pid.Igain                   0
setp J1_pid.Pgain                   0
setp J1_pid.bias                    0
setp J1_pid.command-deriv           0
setp J1_pid.deadband                0
setp J1_pid.error-previous-target   TRUE
setp J1_pid.feedback                0
setp J1_pid.feedback-deriv          0
setp J1_pid.index-enable            FALSE
setp J1_pid.maxcmdD                 0
setp J1_pid.maxcmdDD                0
setp J1_pid.maxcmdDDD               0
setp J1_pid.maxerror                0
setp J1_pid.maxerrorD               0
setp J1_pid.maxerrorI               0
setp J1_pid.maxoutput               0
setp J1_pid.tune-cycles             0x00000032
setp J1_pid.tune-effort             0.5
setp J1_pid.tune-mode               FALSE
setp J1_pid.tune-start              FALSE
setp J1_pid.tune-type               0x00000000
setp J1_switch.home-pos             1
setp J1_switch.hysteresis           0.1
setp J1_switch.index-delay-ms       10
setp J1_switch.index-enable         FALSE
setp J2_pid.Dgain                   0
setp J2_pid.FF0                     1
setp J2_pid.FF1                     0
setp J2_pid.FF2                     0
setp J2_pid.FF3                     0
setp J2_pid.Igain                   0
setp J2_pid.Pgain                   0
setp J2_pid.bias                    0
setp J2_pid.command-deriv           0
setp J2_pid.deadband                0
setp J2_pid.error-previous-target   TRUE
setp J2_pid.feedback                0
setp J2_pid.feedback-deriv          0
setp J2_pid.index-enable            FALSE
setp J2_pid.maxcmdD                 0
setp J2_pid.maxcmdDD                0
setp J2_pid.maxcmdDDD               0
setp J2_pid.maxerror                0
setp J2_pid.maxerrorD               0
setp J2_pid.maxerrorI               0
setp J2_pid.maxoutput               0
setp J2_pid.tune-cycles             0x00000032
setp J2_pid.tune-effort             0.5
setp J2_pid.tune-mode               FALSE
setp J2_pid.tune-start              FALSE
setp J2_pid.tune-type               0x00000000
setp J2_switch.home-pos             1
setp J2_switch.hysteresis           0.1
setp J2_switch.index-delay-ms       10
setp J2_switch.index-enable         FALSE
setp axis.a.eoffset-clear           FALSE
setp axis.a.eoffset-counts          0
setp axis.a.eoffset-enable          FALSE
setp axis.a.eoffset-scale           0
setp axis.a.jog-accel-fraction      1
setp axis.a.jog-counts              0
setp axis.a.jog-enable              FALSE
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

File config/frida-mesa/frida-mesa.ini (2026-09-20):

[EMC]
MACHINE = Frida Mesa 7I95T Commissioning
DEBUG = 0
VERSION = 1.1

[DISPLAY]
DISPLAY = axis
EDITOR = nano
POSITION_OFFSET = MACHINE
POSITION_FEEDBACK = ACTUAL
INCREMENTS = 10mm 1mm 0.1mm 0.01mm 0.001mm
DEFAULT_LINEAR_VELOCITY = 5
MIN_LINEAR_VELOCITY = 0.5
MAX_LINEAR_VELOCITY = 35
MIN_FEED_OVERRIDE = 0
MAX_FEED_OVERRIDE = 1.5
MIN_SPINDLE_OVERRIDE = 0.3
MAX_SPINDLE_OVERRIDE = 1.5
DEFAULT_SPINDLE_SPEED = 800
PROGRAM_PREFIX = ./nc_files
INTRO_GRAPHIC = linuxcnc.gif
INTRO_TIME = 2

[KINS]
JOINTS = 3
KINEMATICS = trivkins coordinates=XYZ

[FILTER]
PROGRAM_EXTENSION = .png,.gif,.jpg Grayscale Depth Image
png = image-to-gcode
gif = image-to-gcode
jpg = image-to-gcode

[TASK]
TASK = milltask
CYCLE_TIME = 0.010

[RS274NGC]
PARAMETER_FILE = frida-mesa.var

[EMCMOT]
EMCMOT = motmod
COMM_TIMEOUT = 1.0
COMM_WAIT = 0.010
SERVO_PERIOD = 1000000

[HAL]
HALUI = halui
HALFILE = mesa.hal
HALFILE = general-signals.hal
HALFILE = hy-vfd.hal
HALFILE = pendant.hal
HALFILE = motion.hal

[HALUI]

[HOSTMOT2]
BOARD_IP = 192.168.1.121

[HY_VFD]
DEVICE = /dev/serial/by-id/usb-1a86_USB_Serial-if00-port0
BAUD = 19200
TARGET = 1

[TRAJ]
COORDINATES = XYZ
LINEAR_UNITS = mm
ANGULAR_UNITS = degree
DEFAULT_LINEAR_VELOCITY = 5
MAX_LINEAR_VELOCITY = 35
NO_FORCE_HOMING = 0

[EMCIO]
EMCIO = io
CYCLE_TIME = 0.100
TOOL_TABLE = tool.tbl
TOOL_CHANGE_AT_G30 = 0

[AXIS_X]
MIN_LIMIT = 61
MAX_LIMIT = 571
MAX_VELOCITY = 35
MAX_ACCELERATION = 85

[AXIS_Y]
MIN_LIMIT = 14
MAX_LIMIT = 491
MAX_VELOCITY = 35
MAX_ACCELERATION = 85

[AXIS_Z]
MIN_LIMIT = -130
MAX_LIMIT = 0.5
MAX_VELOCITY = 35
MAX_ACCELERATION = 85

[JOINT_0]
TYPE = LINEAR
MIN_LIMIT = 61
MAX_LIMIT = 571
MAX_VELOCITY = 35
MAX_ACCELERATION = 85
FERROR = 0.01
MIN_FERROR = 0.001
SCALE = 80
STEPGEN_MAX_VEL = 36
STEPGEN_MAX_ACC = 106.25
DIRSETUP = 5000
DIRHOLD = 5000
STEPLEN = 337500
STEPSPACE = 2500
HOME = 62
HOME_OFFSET = 60
HOME_SEARCH_VEL = -30
HOME_LATCH_VEL = -2
HOME_IGNORE_LIMITS = YES
HOME_USE_INDEX = NO
HOME_SEQUENCE = 1

[JOINT_1]
TYPE = LINEAR
MIN_LIMIT = 14
MAX_LIMIT = 491
MAX_VELOCITY = 35
MAX_ACCELERATION = 85
FERROR = 0.01
MIN_FERROR = 0.001
SCALE = 80
STEPGEN_MAX_VEL = 36
STEPGEN_MAX_ACC = 106.25
DIRSETUP = 5000
DIRHOLD = 5000
STEPLEN = 337500
STEPSPACE = 2500
HOME = 490
HOME_OFFSET = 492
HOME_SEARCH_VEL = 30
HOME_LATCH_VEL = 2
HOME_IGNORE_LIMITS = YES
HOME_USE_INDEX = NO
HOME_SEQUENCE = 1

[JOINT_2]
TYPE = LINEAR
MIN_LIMIT = -130
MAX_LIMIT = 0.5
MAX_VELOCITY = 35
MAX_ACCELERATION = 85
FERROR = 0.01
MIN_FERROR = 0.001
SCALE = -80
STEPGEN_MAX_VEL = 40
STEPGEN_MAX_ACC = 106.25
DIRSETUP = 5000
DIRHOLD = 5000
STEPLEN = 200000
STEPSPACE = 2500
HOME = 0
HOME_OFFSET = 1
HOME_SEARCH_VEL = 14
HOME_LATCH_VEL = 2
HOME_IGNORE_LIMITS = YES
HOME_USE_INDEX = NO
HOME_SEQUENCE = 0

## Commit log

2026-09-19 Add initial LinuxCNC configuration and hardware documentation
    - add Arch Linux installation and real-time tuning notes
    - add Mesa 7I95T latency benchmark configuration
    - add machine configuration and CPU/IRQ affinity scripts
    - preserve legacy BeagleBone Black and Panther Cape documentation
    - add current hardware manuals and VFD register backup
    - add GPLv3 license and repository ignore rules
    [cape-schema-2018-12-19-23-27-52.sch, cape-schema.kicad_pcb, cape-schema.sch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]
2026-09-20 organize LinuxCNC configs and remote workflows
    - move the Frida commissioning profile under config and merge its documentation
    - split hardware documentation into task-specific topic files
    - add scoped agent guidance and Mesa/VFD workflow skills
    - add a consolidated Mesa benchmark counter watcher
    - document the frida sync and remote-execution workflow
    - add pre-commit redaction and sensitive-content checks
    [general-signals.hal, hy-vfd.hal, mesa.hal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]
2026-09-20 adds 7i95 CAD file
    [7i95.step]
2026-09-23 adds bracket for mesa card
    [mesa-card-bracket.FCStd]
2026-09-23 add Mesa communication diagnostic monitor
    Record baseline, heartbeat, timing peak, packet error, NIC, IRQ, and
    realtime-thread data for investigating intermittent 7I95T communication
    errors. Keep generated logs private and ignored by Git, with an optional
    timing-maximum reset mode.
2026-09-25 rename Mesa benchmark paths and launchers
    [mesa-7i95t-bench-1ms.hal, mesa-7i95t-bench-1ms_cmds.hal, mesa-7i95t-bench-2ms.hal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]
